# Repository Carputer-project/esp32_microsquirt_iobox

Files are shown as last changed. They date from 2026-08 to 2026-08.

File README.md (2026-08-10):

# ESP32 MicroSquirt I/O box

DIY clone of the official MicroSquirt "I/O-box" — an **ESP32 + SN65HVD230** that
listens to the MS2/Extra MicroSquirt CAN realtime broadcast (base ID `0x5F0`,
500 kbps) and drives **fan**, **idle control (IAC)** and **6 generic low-side
outputs**, with the same fail-safe the real I/O-box uses (outputs off when CAN
goes silent).

Because MS2/Extra has no I/O-box slave protocol (that's an MS3-only feature), this
box is an **autonomous "smart slave"**: it computes its own output logic from the
broadcast data. It also implements the full **Megasquirt 29-bit expansion
protocol** as a responder (so an MS2/Extra master *can* drive its outputs/ADC
directly), and broadcasts a small **`0x710`** frame for the in-dash HMI.

Works with **any MS2/Extra 3.4.x MicroSquirt V3** — no fuel/spark tune changes
needed, only CAN broadcast settings.



## Features

- **Fan** — CLT hysteresis (on ≥ 200 °F / off ≤ 190 °F default, adjustable) or
  manual override, driven through a ULN2003A channel (default O6/GPIO23).
- **IAC** — 30 Hz PWM on GPIO32 → IRLZ44N → 3-wire rotary ISCV. Three modes:
  **Auto** (CLT warm-up table + RPM trim), **Follow** (mirror the ECU's own
  `iacstep` → fully TunerStudio-tunable closed-loop idle), or **Manual**.
- **O1–O6** — generic low-side outputs (ULN2003A): manual, CLT-temp or RPM
  trigger. O1 defaults to a 7000 rpm shift light.
- **Inputs drive outputs** — A1–A4 analog (0-5 V, 0.15 V hysteresis) can force any
  output or the fan (I/O-box parity).
- **29-bit CAN responder** — MS2/Extra remote-port protocol: MSG_REQ/MSG_CMD on
  table 7; remote idle PWM, remote on/off outputs, remote boost, ADC readback.
- **`0x710` dash broadcast** — A1–A4 threshold latches for
  the in-dash HMI (indicator/high-beam/brake icons). 10 Hz, always on.
- **GC9A01A round gauge** — 1.28" 240×240 idle-control display: big IAC duty %,
  RPM / target RPM / CLT / idle mode, fan + CAN status line.
- **Fail-safe** — all outputs off after 500 ms without CAN (matches the real
  I/O-box); IAC falls back to the ~1000-1200 rpm valve default.
- **Persistent config** — all settings stored in NVS; loadable/settable over
  serial or via the included Windows diagnostic app.

## Repo layout

```
esp32_microsquirt_iobox/
├── firmware/            PlatformIO ESP32 firmware — iobox2 (round display)
├── firmware-v3/         PlatformIO ESP32 firmware — iobox3 (configurable pins, display opt-in)
├── pcb/                 KiCad 8 PCB design (iobox2: schematic, board, project)
├── diag/                iobox_diag.py — Windows test/configure app (Python + Tkinter)
└── docs/
    ├── OPERATION.md     How the box works + how to use it (modes, commands, display)
    ├── PROTOCOL.md      CAN protocol reference (0x5F0 broadcast, 0x710, 29-bit responder)
    ├── BUILD.md         Full point-to-point build/wiring guide
    └── PARTS.md         Parts list with rough prices
```

## Two firmware variants

| | `firmware/` (iobox2) | `firmware-v3/` (iobox3) |
|---|---|---|
| Board | ESP32 DevKit + breakout, GC9A01A round display | Bare ESP32-WROOM-32 module board, 7" dash on CAN is the HMI |
| IAC pin | 32 (compile-time) | **runtime-configurable** (`P` command / diag app Pins tab) |
| Outputs | O1-O6 = 25,26,27,14,13,23 (compile-time) | O1-O7 = 13,12,14,27,26,25,33 default, **runtime-configurable** |
| Round display | yes | opt-in (`P TFT 1`; GPIO19 conflicts with IAC) |
| Switches | none (removed) | none |
| Use `P`? | no (fixed pins) | yes |

Both share the same core (CAN broadcast decode, fan, IAC, outputs, engine
profile warnings, 29-bit responder, `0x710` dash broadcast). iobox2 = one build
for that board; iobox3 = one firmware, pin map set once per board via the
diag app.

## Quick start

1. **Build hardware** — see `docs/BUILD.md` (wiring) and `docs/PARTS.md` (parts).
   The KiCad design in `pcb/` is the iobox2 board; the point-to-point
   build guide is an alternative for module wiring without a PCB. iobox3 is the
   bare-module 3×3 board — see `firmware-v3/README.md`.
2. **Flash firmware** (pick the folder matching your board):

   ```sh
   cd firmware        # iobox2  — or:  cd firmware-v3  for iobox3
   pio run                 # build
   pio run --target upload # flash over USB
   pio device monitor -b 115200
   ```

   Requires PlatformIO (ESP32 Arduino framework). At the serial prompt type `?`
   for a live status dump. On iobox3, type `P` to see the pin map (set it once
   from the diag app's Pins tab if your board is wired differently).
3. **Configure the MicroSquirt (one time)** in TunerStudio → CAN Realtime Data
   Broadcasting: **On**, base ID **1520**, rate **20 Hz**, enable groups
   **00** (rpm), **02** (baro/map/mat/clt), **03** (tps/batt/afr), and optionally
   **06** (iacstep) for Follow mode. Details in `docs/OPERATION.md`.
4. **Use the Windows app** (`diag/iobox_diag.py`) to set fan thresholds, IAC mode,
   output triggers, input mappings, the 29-bit responder and (iobox3) the pin map
   from a GUI.

## Hardware snapshot

| GPIO | Function | Drives |
|---|---|---|
| 5 / 4 | CAN TX / RX | SN65HVD230 (MicroSquirt pins 2/3, CANH/CANL) |
| 32 | IAC PWM (30 Hz) | ISCV via IRLZ44N |
| 25,26,27,14,13,23 | O1–O6 | ULN2003A (O6 = fan by default, `Y<k>` to change) |
| 2 | Status LED | onboard (CAN heartbeat / fail-safe blink) |
| 36,39,34,35 | A1–A4 analog 0-5 V | 10k/20k divider (or PCB 12 V→3.3 V dividers) |
| 15,21,22,19 | GC9A01A round display | SCLK / MOSI / CS / DC |

All outputs are **low-side (ground-switching)**, like the real MS I/O-box. Never
feed 12 V into the ESP32 or SN65HVD230 — a 12 V→5 V buck is mandatory.

## Serial command cheat sheet

| Command | Effect |
|---|---|
| `?` | status dump |
| `F205` / `F1` / `F0` | fan auto @205 °F / manual on / off |
| `E190` | fan off hysteresis 190 °F |
| `I35` / `I` / `I F` | IAC manual 35% / auto / follow-ECU |
| `T900` | idle target 900 rpm (auto mode) |
| `S7000` | shift light @7000 rpm |
| `O3 R3500` / `O4 1` | O3 above 3500 rpm / O4 on |
| `A1 O2 3.5` / `A2 F 2.0` | analog threshold → output/fan |
| `Y6` | fan on ULN channel 6 |
| `R1` / `R0` / `RB5` | 29-bit responder on/off / box ID |
| `W1` / `W0` | engine profile monitoring on/off |
| `W idle 650 1000` | idle RPM band (warning below/above, <20% TPS) |
| `W clt 230` / `W mat 160` | max coolant / intake °F |
| `W batt 11.0 16.0` / `W map 280` | battery band / max MAP kPa |
| `W afr 10.0 16.5` | AFR window (below=RICH, above=LEAN) |
| `W hold 3000` / `W warnout 3` | warn latch ms / blink O3 as check-engine lamp |
| `P IAC 19` / `P O3 27` | **iobox3 only** — set IAC / output pin |
| `P RESET` | iobox3 only — restore default pin map |
| `S` | full command list |

## CAN at a glance

- **ECU → box**: 11-bit IDs `0x5F0`–`0x5F8` (group N at ID 1520+N), big-endian,
  8 bytes/group, 20 Hz. rpm@6, baro/map/mat/clt@16-22 (×0.1), tps/batt/afr@24-28
  (×0.1), iacstep@54 (×0.392 = duty %).
- **Box → dash**: `0x710`, byte0 = A1–A4 latches, byte1 = reserved, byte2 = counter.
- **Master → box**: 29-bit extended `MSG_REQ`/`MSG_CMD` (MS2/Extra remote ports).

Full byte maps and the 29-bit responder spec: `docs/PROTOCOL.md`.

## Project context

Built for a 7A-GTE (7A block + 4A-GE head) MicroSquirt V3 car: the I/O box frees
the ECU's FIDLE (moving boost control off it), adds proper PWM idle via the ISCV,
handles the radiator fan, and feeds warning-lamp states (indicators, high beam,
brake) to a 7" ESP32-S3 in-dash HMI. This box is one of several open-source
modules in the [Carputer-project](https://github.com/Carputer-project)
ecosystem.

## License

Firmware, PCB and tooling in this repo are released for personal/DIY use.
See each file header for notes.

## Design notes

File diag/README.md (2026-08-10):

# iobox_diag — Windows test/configure app

Single-file **Python 3 + Tkinter** GUI for the ESP32 MicroSquirt I/O box. It
talks the same text command language the box exposes on its serial console, so
every action maps 1:1 to the serial reference in `../docs/OPERATION.md` §9.

![dependency: python3 + tkinter + optional pyserial]

## Run

```sh
pip install pyserial      # only needed for the USB path
python iobox_diag.py      # python3 on Linux/macOS
```

No Qt needed. Works on Windows too (uses `python`, `pip`).

## What it does

| Tab | Purpose |
|-----|---|
| Fan | auto / manual on-off, on-threshold (°F), off-threshold (°F), output channel (`Y1-7`) |
| IAC | auto / follow-ECU / manual duty, target idle rpm |
| Outputs | per-output manual on/off, temp trigger, rpm trigger (O1-O7) |
| Inputs | A1-A4 analog → target + threshold volts |
| Engine | engine-profile limits grid (idle/maxrpm/clt/mat/batt/map/afr/hold/warnout) |
| Pins | **IAC + output GPIO map** — board presets (iobox2 / iobox3), edit, apply (`P` cmds), read from box |
| Advanced | 29-bit CAN responder enable/disable/box-ID, shift-light rpm |
| Console | raw command line, `?` status button, scrolling RX log |

## Transport

- **USB (default, active)**: `pyserial`, 115200 baud. Pick the COM port and
  Connect.
- **WiFi/TCP**: the radio is currently **disabled** ("WiFi pending (firmware)") —
  the box firmware has no WiFi server yet. The TCP transport code
  (`IoBox.connect_tcp`, default `192.168.4.1:23`) is left in place for when the
  box grows a soft-AP command port.

## Design notes

- `IoBox` class: serial or TCP link, background reader thread → `queue.Queue` →
  `poll()` drains to the UI. `on_line` / `_poll` keep the console live at 50 ms.
- The box persists every setting in NVS; the app just sends commands.
- Status responses (e.g. `?`) come back as `can_fresh=... rpm=...` lines in the
  console — parse-friendly for future automation.

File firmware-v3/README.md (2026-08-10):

# ESP32 MicroSquirt I/O box v3 (iobox3)

Third-generation I/O box for MicroSquirt/MS2-extra. **Single firmware for every
board** — iobox2's round display is merged in (opt-in), and
**output + IAC pins are runtime-configurable** and stored in NVS, so one firmware
serves any WROOM-32 board.

## Pin map (default = iobox3 board)

Configurable at runtime (persisted in NVS) via the `P` command or the diag app's
**Pins** tab:

| Function | Default GPIO | Configurable |
|---|---|---|
| IAC PWM (LEDC 30 Hz) | 19 | yes (`P IAC <pin>`) |
| O1-O7 (ULN2003A low-side) | 13, 12, 14, 27, 26, 25, 33 | yes (`P O<n> <pin>`) |
| CAN TX / RX | 5 / 4 | no (compile-time) |
| Analog A1-A4 | 36, 39, 34, 35 | no (compile-time) |
| Round display (GC9A01A) | 15, 21, 22, 19 | no (compile-time), **opt-in** |
| Status LED | 2 | no (compile-time) |

Board presets are built into the diag app:
- **iobox2**: IAC 32, O1-O6 25/26/27/14/13/23 (+ O7 spare 33), display **on**
- **iobox3**: IAC 19, O1-O7 13/12/14/27/26/25/33, display **off**

Changing a pin takes effect immediately (`applyPinConfig()` reconfigures GPIO modes
and re-attaches LEDC) and survives reboot via NVS.

## Round display (opt-in)

The GC9A01A round gauge (idle duty % center, RPM/TGT/CLT/MODE quadrants, warning
blink, CAN status bar) is compiled in but **disabled by default** because
TFT DC = GPIO19 clashes with iobox3's IAC pin. On a bench dev board (or any board
wired like iobox2) enable it with:

```
P IAC 32    # move IAC off GPIO19 (use the iobox2 preset)
P TFT 1     # enable display (persisted)
```

`P TFT 0` disables it again. The display repaints at 10 Hz.

## Rejected pins

`P` refuses to map these GPIOs (boot straps, console UART, LED, CAN, dead, or
input-only): 0, 1, 2, 3, 4, 5, 6-11, 20, 24, 28-31, 34, 35, 36, 39.

## Serial commands

Everything from iobox2 plus:

| Command | Effect |
|---|---|
| `P` | report current pin map |
| `P IAC 19` | set IAC pin |
| `P O3 27` | set O3 pin |
| `P TFT 1` / `P TFT 0` | enable / disable round display (persisted) |
| `P RESET` | restore iobox3 defaults (persisted) |

Full iobox2 command set (F/E/I/T/Y/S/O/A/R/W) is unchanged — see
`../esp32_ms_iobox/README.md`. The `D` (switch) command is gone — switches were
removed from the firmware.

## Build & flash

```
pio run                         # build
pio run --target upload         # flash over USB
pio device monitor -b 115200    # serial console
```

## Diag app

`~/Desktop/carputer/iobox_diag/iobox_diag.py` gained a **Pins** tab: pick a board
preset, edit the GPIO fields, Apply to box. Read-from-box (`P`) parses the reply
into the fields automatically.

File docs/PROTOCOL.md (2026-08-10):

# CAN protocol reference

Three independent streams live on the bus:

1. **ECU → box**: 11-bit broadcast `0x5F0`+ (MS2/Extra outpc groups).
2. **Box → dash**: 11-bit `0x710` (input states for the in-dash HMI).
3. **Master → box**: 29-bit extended `MSG_REQ` / `MSG_CMD` (Megasquirt expansion
   protocol; MS2/Extra remote ports).

All frames are **500 kbps**. The MicroSquirt V3 has an internal CAN terminator;
the SN65HVD230 module's 120 Ω jumper is the other end of a 2-node bus.

---

## 1. ECU broadcast — `0x5F0` … `0x5F8` (11-bit, 20 Hz, big-endian)

MS2/Extra MicroSquirt broadcasts its `outpc` structure 8 bytes per group, group N
at ID `1520 + N`. Offsets are the `outpc` offsets from `microsquirt-module.ini`
(`ochBlockSize = 212`). Enabled groups: 00, 02, 03 (+ 06 for Follow mode).

| ID | Grp | Byte | Channels (offset, type, scale) |
|----|-----|---|---|
| 0x5F0 | 00 | 0-7 | seconds u16@0, pw1 u16@2, pw2 u16@4, **rpm u16@6** |
| 0x5F1 | 01 | 8-15 | advance s16@8 (×0.1°), flags, afrtgt1/2, wbo2 |
| 0x5F2 | 02 | 16-23 | **baro s16@16**, **map s16@18**, **mat s16@20**, **clt s16@22** (all ×0.1) |
| 0x5F3 | 03 | 24-31 | **tps s16@24**, **batt s16@26**, **afr1 s16@28**, afr2 s16@30 (×0.1) |
| 0x5F4 | 04 | 32-39 | knock u16@32, egocor1 s16@34, egocor2 s16@36, aircor s16@38 |
| 0x5F5 | 05 | 40-47 | warmcor s16@40, tpsaccel s16@42, tpsfuelcut s16@44, barocor s16@46 |
| 0x5F6 | 06 | 48-55 | totalcor s16@48, ve1 s16@50, ve2 s16@52, **iacstep s16@54** |
| 0x5F7 | 07 | 56-63 | coldadv s16@56, TPSdot s16@58, MAPdot s16@60, dwell u16@62 |

Notes:

- All values big-endian; temperatures in °F (×10), pressures in kPa (×10).
- `iacstep` (offset 54) is the ECU's idle valve duty raw 0-255; **duty % =
  `iacstep × 0.392`**. Used by Follow mode (TS `IdleCtl = PWM valve`).
- Group 08 (0x5F8, outpc 64-71) carries portStatus/knockRetard — reserved.

The box's TWAI filter is accept-all (`0xFFFFFFFF`); software ignores IDs outside
`0x5F0`–`0x5F8`, plus `0x600` (commands) and extended frames.

---

## 2. Box → dash — `0x710` (11-bit, 8 bytes, 10 Hz, always on)

Broadcast by the box itself (not the ECU), so it keeps running even if the ECU
bus drops. Carried the input states for the in-dash HMI.

| Byte | Bits | Meaning |
|---|---|---|
| 0 | 0-3 | A1–A4 threshold latches (1 = analog input above its `A<n>` trigger) |
| 1 | — | reserved (0) |
| 2 | all | frame counter (rollover) |
| 3-7 | — | reserved (0) |

The dash decodes this alongside `0x5F0`–`0x5F8` to render indicator / high-beam /
brake icons. The ECU ignores `0x710` (not a group it broadcasts or listens to).

**iobox2 PCB analog dividers** (indicator L, indicator R, high beam, brake
lights): 12 V signals → divider → A1–A4. Ratio must be ≈ 1/4.8 so the GPIO sees
≤ 3.3 V at 14.4 V running voltage. Recommended resistor pairs (series / to-GND):
**33 kΩ / 8.2 kΩ**, 10 kΩ / 2.7 kΩ, 30 kΩ / 7.5 kΩ, or 47 kΩ / 12 kΩ. Avoid
10 kΩ + 3.9 kΩ (≈4.03 V at 14.4 V). Add a 0.1 µF cap GPIO→GND per input; the
firmware's 0.15 V hysteresis is built in. Thresholds are set from what the diag
app reports (board reports GPIO volts × `ADC_DIVIDER` = 1.5).

---

## 3. 29-bit expansion responder — MSG_REQ / MSG_CMD

The box implements the responder side of the Megasquirt 29-bit MS-CAN protocol,
so an MS2/Extra master can directly drive remote outputs and read remote ADC/ports
(MS2/Extra has full remote-port support in 3.4.4 — only the *official* MS2
I/O-box firmware is broadcast-only).

### 3.1 Header (29-bit extended identifier)

```
bit 28 .. 19 : offset      (11 bits, 0x000-0x7FF)
bit 18 .. 16 : type        (3 bits)
bit 15 .. 12 : from_id     (4 bits)
bit 11 ..  8 : to_id       (4 bits)
bit  7 ..  4 : table       (4 bits)
bit  3 ..  0 : table[bit4] (1 bit rides wire bit 2)
```

Equivalently `id = (offset<<18) | (type<<15) | (from<<11) | (to<<7) | (table<<3)`
with the table bit-4 folded into bit 2 (see `respMakeId()` in `main.cpp`).

Types: 0 = MSG_CMD, 1 = MSG_REQ, 2 = MSG_RSP, 4 = MSG_BURN, 5 = OUTMSG_REQ,
6 = OUTMSG_RSP, 12 = MSG_REQX, 0x80 = MSG_PROT, 0x82 = MSG_SPND.

IDs: 0 = ECU, 1-14 = boxes, 15 = broadcast. The ECU accepts `to_id` 0 or 15; the
box accepts `to_id` = its box ID (`respId`, default 5) or 15.

### 3.2 MSG_REQ (read box table) — DLC 3

| DSR | Meaning |
|-----|---|
| 0 | `rem_table` (box echoes it in the reply header) |
| 1 | `rem_off >> 3` (offset bits 10-3) |
| 2 | `((rem_off & 7) << 5) | rem_by` (offset bits 2-0, count 1-8) |

Reply = **MSG_RSP**: header offset = `rem_off` (echo), table = `rem_table` (echo),
from = box, to = requester; DLC = `rem_by`, data = `rem_by` bytes from
`box.tables[rem_table][rem_off]`. The ECU stores the reply into `outpc` at the
echoed offset — **echo `rem_off` and exactly `rem_by` bytes** or the ECU
overwrites unrelated outpc.

### 3.3 MSG_CMD (write box table) — DLC 1-8

Data bytes are stored at `tables[header.table][header.offset]`. For the port
table (default offset 75, auto-detected from the first 1-3 byte write):

| Byte | Meaning |
|---|---|
| 0 | bits 0-5 = O1–O6 on; bit 0x40 = fan on |
| 1 | ISCV duty raw (×100/255 = %) |
| 2 | reserved |

Remote drive is active while port frames stay fresh (< 500 ms); otherwise the
box falls back to autonomous logic, and with no ECU broadcast at all it goes
fail-safe. Input forces (D/A triggers) always OR in.

### 3.4 Box table 7 (256-byte response table)

| Offset | Contents |
|---|---|
| 0-7 | gpioadc0-3 (A1–A4, big-endian mV) |
| 8-15 | gpioadc4-7 (unused, 0) |
| 16-23 | gpiopwmin (unused) |
| 24-74 | free |
| 75-77 | remote ports (see §3.3) |

MSG_REQ reads any offset back; MSG_CMD writes any offset.

### 3.5 TunerStudio setup for remote-port control

```
CAN Parameters        → Master Enable: Enable
Enable poll ports     → enable_pollports: Enable
can_poll_id0-3        → 5 (box ID)
poll_tableports       → 7
poll_offsetports      → 75
ports_dir             → "3 Outputs"
port_generic          → "Remote Port 1"
pwmidle_port2         → "Remote Port 2"
IdleCtl               → PWM valve (open or closed loop)
Group 06              → enable (so Follow-mode fallback + display work)
```

The 0x5F0 broadcast + Follow mode remains available as a parallel, ECU-agnostic
path; the responder and broadcast can be used together or independently.

---

## 4. Box command channel — `0x600` (11-bit, optional)

Any 11-bit frame to ID `0x600` is treated as a serial command string (max 8
bytes, null-terminated): e.g. `F1`, `I F`, `?`. Same parser as the serial port.
Useful for remote reconfiguration over the bus.

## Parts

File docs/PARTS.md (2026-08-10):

# ESP32 MicroSquirt I/O box — Parts list & wiring

Everything needed to build the I/O box. Prices are rough street prices (AliExpress/
DigiKey/Mouser/local); totals assume AliExpress quantities.

## 1. Required parts

| Qty | Part | Purpose | Est. cost |
|-----|---|---|---|
| 1 | ESP32 DevKit (WROOM-32), 30-pin | main controller | $4-8 |
| 1 | SN65HVD230 CAN transceiver module | CAN bus interface (3.3V) | $2-3 |
| 1 | IRLZ44N logic-level N-MOSFET (TO-220) | IAC low-side switch | $1-2 |
| 1 | ULN2003A driver IC (DIP-16 or breakout) | 6 generic low-side outputs O1-O6 (+ fan channel) | $1-2 |
| 1 | 12V→5V buck module (MP1584 / LM2596) | powers logic — do NOT feed 12V into the ESP32 | $2-3 |
| 1 | 4A-GE/7A-FE ISCV (3-wire rotary solenoid) | idle control valve (IAC function only) | spare/used |

Core total: **~$10-20**

## 2. Resistors

| Value | Qty | Where | Required? |
|---|-----|---|---|
| 10kΩ + 20kΩ | 4 pairs | A1-A4 input dividers: sensor → 10k → GPIO, sensor → 20k → GND (GPIO sees 2/3 of input; 0-5V → 0-3.3V) | yes |
| 10kΩ | 1 | gate pull-down on the IRLZ44N gate (keeps MOSFET OFF during ESP32 boot while GPIO floats) | recommended |
| 100Ω-1kΩ | 1 | gate series resistor (slow switching edge, reduce noise) | optional |
| 120Ω | 1 | bus termination — only if the SN65HVD230 module lacks its termination jumper (the MicroSquirt V3 already has its own terminator) | only then |

## 3. Protection components (recommended)

| Part | Qty | Where |
|---|-----|---|
| 1N5404 or 1N4007 flyback diode | 1 | across the ISCV (cathode to +12V) — kills inductive kickback that would destroy the MOSFET. Fan kickback is handled by the ULN2003A internal flyback diodes |
| 0.1µF ceramic cap | 4 | 1 per analog input, GPIO → GND — filters sensor noise |
| Inline fuse 2-5A fast-blow | 1 | on the 12V feed into the buck module |

## 4. Wiring summary

### CAN
```
uS pin 2 (CANH, Blue/Yellow)  → SN65HVD230 CANH
uS pin 3 (CANL, Blue/Red)     → SN65HVD230 CANL
ESP32 GPIO5 (TX)              → SN65HVD230 CTX
ESP32 GPIO4 (RX)              → SN65HVD230 CRX
```
MicroSquirt V3 has an internal terminator; the SN65HVD230 module's 120Ω jumper is the
other end (2-node bus). Keep it ON.

### ESP32 pin map
| GPIO | Function |
|---|---|
| 5 / 4 | CAN TX / RX → SN65HVD230 |
| 32 | IAC PWM → IRLZ44N gate → ISCV |
| 25,26,27,14,13,23 | O1-O6 → ULN2003A inputs (O6 = fan by default) |
| 2 | status LED (onboard) |
| 36,39,34,35 | A1-A4 analog (via 10k/20k divider) |
| 15,21,22,19 | GC9A01 display SCLK/MOSI/CS/DC |

### MOSFET stage (IAC — ×1)
```
GPIO → [optional 100Ω] → gate ── 10kΩ → GND
source → GND
drain  → load low side (load other end to +12V)
flyback diode across load (cathode → +12V)
```

### ULN2003A stage (O1-O6 + fan)
```
GPIO → ULN2003A IN pin directly (built-in 2.7kΩ base resistor)
ULN2003A OUT pin → relay coil / device to +12V (internal flyback diodes)
Fan (default = OUT6): fan − → OUT<fanOut>, fan + → +12V; ULN COM → +12V.
Use a relay for fans drawing > ~500 mA (ULN channel limit).
```

### Analog inputs (×4)
```
sensor signal (0-5V) → 10kΩ → GPIO
                    → 20kΩ → GND
optional 0.1µF cap: GPIO → GND
```

### Switches

None — D1-D3 switch inputs were removed from the firmware. GPIOs 16/17/18 are
unused on the board.

### Power
```
+12V → fuse → buck in → 5V out → ESP32 5V pin
ESP32 GND = buck GND = SN65HVD230 GND = uS signal ground (all common)
```

## 5. Notes / cautions

- **Never** feed 12V into the ESP32 or SN65HVD230 — the buck module is mandatory.
- ISCV is a **3-wire rotary solenoid** (center = +12V, one outer = GND, one outer =
  IRLZ44N drain). PWM duty >50% opens, <50% closes — swap the outer pins to invert.
  Do NOT use a stepper driver with this valve.
- If running the IAC output, leave the 3.3V/5V off the gate — these are low-side,
  ground-switching drivers.
- All outputs are low-side (ground-switch) exactly like the real MS I/O-box.
- Fan rides a ULN2003A channel (`fanOut`, default 6 = O6). ULN channels are ~500 mA —
  run a big radiator fan through a relay driven by a ULN channel instead.

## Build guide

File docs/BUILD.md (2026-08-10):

# ESP32 MicroSquirt I/O box — Point-to-point build

DIY clone of the MS I/O-box: ESP32 + SN65HVD230 reads the MicroSquirt CAN broadcast
(base ID 0x5F0, 500k) and drives fan, IAC, and 6 generic low-side outputs. Fail-safe:
all outputs off after 500 ms no CAN.

Build style: **module-to-module point-to-point wiring** — no unified PCB. ESP32 comes
with a pinout board / screw terminals; every module (CAN transceiver, MOSFETs, ULN2003A,
buck) wires directly to it.

---

## 1. Block diagram

```
                        ┌──────────────────────────────┐
                        │         +12V switched         │
                        └──────┬───────────────────────┘
                               │
                          [ 2-5A fuse ]
                               │
                       ┌───────┴────────┐
                       │  MP1584/LM2596 │  buck 12V→5V
                       │  buck module   │
                       └───┬────────┬───┘
                           │ 5V     │ GND
                           │        │
        ┌──────────────────┼────────┼──────────────────────────┐
        │                  │        │                          │
   ┌────┴─────┐      ┌─────┴────┐   │                    ┌─────┴─────┐
   │  ESP32   │      │SN65HVD230│   │                    │  MicroSq. │
   │ DevKit   │      │ CAN trx  │   │                    │  V3 (uS)  │
   │ 30-pin   │      │          │   │                    │           │
   └─┬──┬──┬──┘      └──┬────┬──┘   │                    └─────┬─────┘
     │  │  │            │    │      │                          │
     │  │  │   GPIO4 RX─┘    └─GPIO5 TX                       │
     │  │  │            │          │                          │
     │  │  │       CANH └──────────┼────────── uS pin 2 (CANH, Blue/Yellow)
     │  │  │       CANL ───────────┼────────── uS pin 3 (CANL, Blue/Red)
     │  │  │                       │
     │  │  │   (120Ω termination on SN65HVD230 jumper — uS has its own)
     │  │  │
     │  │  └── GPIO32 → IRLZ44N → ISCV (IAC, 30 Hz PWM)
     │  │
      ├── GPIO25,26,27,14,13,23 → ULN2003A IN1-IN6 → O1-O6 (relays/loads)
      │  │     fan = ULN channel (default O6/GPIO23, Y<k> command to change)
      ├── GPIO2  → status LED (onboard)
      ├── GPIO36,39,34,35 → A1-A4 (0-5V via 10k/20k divider)
      └── GPIO15,21,22,19 → GC9A01 round display (SCLK, MOSI, CS, DC)
```

---

## 2. Wiring diagram (point-to-point)

### 2.1 Power

```
+12V (switched) ──[fuse 2-5A]──┬─ buck IN+
                               └─ fan/ISCV/relay +12V rail
buck OUT 5V ── ESP32 "5V" pin
buck GND ───── ESP32 GND + SN65HVD230 GND + uS signal GND (all common)
```

### 2.2 CAN (MicroSquirt → SN65HVD230 → ESP32)

```
uS pin 2 (CANH, Blue/Yellow) ── SN65HVD230 CANH
uS pin 3 (CANL, Blue/Red)    ── SN65HVD230 CANL
ESP32 GPIO5 (TX)             ── SN65HVD230 CTX
ESP32 GPIO4 (RX)             ── SN65HVD230 CRX
SN65HVD230 120Ω jumper: ON
```

### 2.3 IAC stage — confirmed: 7A rotary-solenoid ISCV (3-wire)

Customer's valve is the **7A-FE/4A-FE rotary solenoid ISCV** (NOT a stepper). 3-wire
connector: **center = +12V (switched)**; one outer pin = **ground**; one outer pin =
**ECU low-side PWM** (IRLZ44N on GPIO32). Duty ratio: **>50% opens, <50% closes**
(swap the two outer pins to invert if it responds backwards). Unpowered, the valve
rests at ~1000-1200 rpm — a natural fail-safe (CAN loss → valve stays near default).

```
+12V rail ── ISCV center pin (+B)
ISCV outer pin (E1/ground side) ── GND
ESP32 GPIO32 ──[100Ω]── gate ──[10kΩ]── GND   (IRLZ44N)
               source ── GND
               drain  ── ISCV remaining outer pin (PWM control)
               [1N5404 across ISCV, cathode→+12V, anode→drain]
```

Firmware: existing PWM mode on GPIO32 already correct (30 Hz low-side duty).
Only tuning: map duty so >50% = open (or rewire outer pins to invert).

**Option B — 4-wire stepper ISCV (22270-16010/16020): H-bridge/stepper driver**

A stepper has 2 coils (4 wires) and CANNOT be driven by one PWM channel. Use a
stepper driver (DRV8825/A4988) or dual H-bridge (L298N).

**NOTE**: the old design reserved GPIO21+GPIO22 for the stepper. Those are now used by
the round display (MOSI, CS). The stepper option is demoted — if a 4-wire valve ever
shows up, rewire the display elsewhere (or run it on a second ESP32). The confirmed
3-wire rotary ISCV (Option A above) is the only supported IAC path. Stepper firmware
is also still pending — current `main.cpp` outputs PWM on GPIO32 only (Option A).

### 2.4 Fan stage (via ULN2003A channel, default O6/GPIO23)

**There is NO dedicated fan MOSFET.** The firmware drives the fan through one of the
ULN2003A channels — `Cfg.fanOut` (default **6** = GPIO23/O6, set with the `Y<k>`
serial command, `Y0` = off). `setFan()` in `main.cpp:127` just pokes that channel and
the output loop skips it (main.cpp:329).

```
fan + wire ── +12V rail
fan − wire ── ULN OUT<fanOut>   (e.g. OUT6)
fan control wire ── (ULN COM → +12V already provides internal flyback)
```

- **Inductive kickback**: handled by the ULN2003A built-in flyback diodes (COM must be
  tied to +12V). No external 1N5404 needed on the fan.
- **Current**: ULN2003A channels are ~500 mA continuous / 350 mA per-channel worst-case
  daisy-chained. If the radiator fan draws more, drive a **relay** from a ULN channel
  instead (ULN OUT → relay coil → +12V, relay contacts switch the fan).
- Default output is O6; if you want the fan on a different channel, set `Y<k>` and wire
  that OUT pin to the fan.

### 2.5 Generic outputs (ULN2003A)

```
ESP32 GPIO25 ── ULN IN1 │ OUT1 ── O1 (shift light 7000 rpm)
ESP32 GPIO26 ── ULN IN2 │ OUT2 ── O2
ESP32 GPIO27 ── ULN IN3 │ OUT3 ── O3
ESP32 GPIO14 ── ULN IN4 │ OUT4 ── O4
ESP32 GPIO13 ── ULN IN5 │ OUT5 ── O5
ESP32 GPIO23 ── ULN IN6 │ OUT6 ── O6 (fan by default — see §2.4)
ULN COM pin ── +12V rail (internal flyback diodes need this)
Each OUT n ── load low side; load + side ── +12V
```

### 2.6 Analog inputs (×4) — 0-5V → 3.3V

```
sensor sig (0-5V) ──[10kΩ]── GPIO36 (A1)
                 └──[20kΩ]── GND
optional 0.1µF cap: GPIO ── GND
same divider for A2/A3/A4 → GPIO39/34/35
```

### 2.7 Analog inputs (A1-A4) — see §2.9 pin table

The box has no switch inputs (D1–D3 removed from firmware). All four GPIO pins
that formerly served switches are unused/available.

### 2.8 Round display (GC9A01A 240×240) — 4-wire SPI

```
display VCC ── 5V      display GND ── GND
display SCL ── GPIO15   display SDA ── GPIO21
display CS  ── GPIO22   display DC  ── GPIO19
display RST ── 3V3 (tied high; reset handled at power-up)
```

Software SPI via the Adafruit GC9A01A library (hardware SPI pins 15/21/22/19 are in
use by other channels). Renders an idle-control gauge: big IAC duty %, actual RPM /
target RPM / CLT / idle mode (AUTO·FOLLOW·MAN), and a bottom fan + CAN status line
(red "CAN LOST" on fail-safe).

### 2.9 Status LED

```
GPIO2 ── onboard LED (CAN heartbeat)   [no wiring needed]
```

---

## 3. ESP32 pin map (summary)

| GPIO | Function | Drives |
|---|---|---|
| 5 | CAN TX | SN65HVD230 CTX |
| 4 | CAN RX | SN65HVD230 CRX |
| 32 | IAC PWM | ISCV via IRLZ44N (30 Hz) |
| 25 | O1 shift light | ULN2003A |
| 26 | O2 | ULN2003A |
| 27 | O3 | ULN2003A |
| 14 | O4 | ULN2003A |
| 13 | O5 | ULN2003A |
| 23 | O6 — fan (default) | ULN2003A |
| 2 | Status LED | onboard |
| 15 | Display SCLK | GC9A01 round display |
| 21 | Display MOSI | GC9A01 round display |
| 22 | Display CS | GC9A01 round display |
| 19 | Display DC | GC9A01 round display |
| 36,39,34,35 | A1-A4 analog 0-5V | via 10k/20k divider to 3.3V |

---

## 4. Parts list

### Required

| Qty | Part | Purpose | Est. cost |
|-----|---|---|---|
| 1 | ESP32 DevKit (WROOM-32) 30-pin with pinout board + screw terminals | main controller | $4-8 |
| 1 | SN65HVD230 CAN transceiver module | CAN interface (3.3V), 120Ω jumper | $2-3 |
| 1 | IRLZ44N logic-level N-MOSFET (TO-220) | IAC low-side | $1-2 |
| 1 | ULN2003A driver IC (DIP-16 or breakout) | O1-O6 low-side + fan channel | $1-2 |
| 1 | 12V→5V buck module (MP1584 / LM2596) | logic power — never feed 12V to ESP32 | $2-3 |
| 1 | ISCV (7A-FE/4A-FE rotary solenoid, **3-wire**) | IAC valve | on car |
| 1 | 1.28" round GC9A01A TFT 240×240 (e.g. Teyleten B0B7TFRNN1) | info gauge, SPI | $3-5 |
| 0-1 | **DRV8825/A4988 or L298N** (only if a 4-wire stepper ISCV is ever used) | stepper driver — NOTE: GPIO21/22 now used by display | $2-4 |

### Resistors

| Value | Qty | Where |
|---|-----|---|
| 10kΩ | 4 | A1-A4 dividers (sensor → GPIO) |
| 20kΩ | 4 | A1-A4 dividers (sensor → GND) |
| 10kΩ | 1 | gate pull-down on IRLZ44N (keeps MOSFET off during ESP32 boot) |
| 100Ω | 1 | optional gate series (noise) |
| 100µF electrolytic | 1 | bulk cap across DRV8825 VMOT/GND (only for stepper option) |

### Protection

| Part | Qty | Where |
|---|-----|---|
| 1N5404 flyback diode | 1 | across ISCV (cathode → +12V). Fan kickback is handled by ULN2003A internal diodes |
| 0.1µF ceramic cap | 4 | 1 per analog input, GPIO → GND |
| 2-5A fast-blow inline fuse | 1 | 12V feed into buck |
| 120Ω resistor | 1 | only if SN65HVD230 module lacks termination jumper |

### Wire / hardware

| Item | Qty | Purpose |
|---|-----|---|
| 18-22 AWG wire (various colors) | roll | power + loads |
| 24 AWG hookup wire | roll | signals (CAN, GPIO) |
| Heat shrink / solder / flux | — | joints |
| Small enclosure or mounting plate | 1 | mount modules |
| Ring/spade terminals + M3 bolts | — | IRLZ44N TO-220 mounting |

---

## 5. Build order (suggested)

1. Buck module: fuse → 12V in, set 5V out, verify with multimeter before connecting ESP32
2. CAN: SN65HVD230 → ESP32 GPIO4/5, then MicroSquirt pins 2/3 (only after power check)
3. MOSFET stage: IRLZ44N + gate pull-down + flyback diode (IAC only)
4. ULN2003A: COM to +12V, wire O1-O6 (+ fan on its channel)
5. Analog dividers A1-A4 + caps
6. Round display: SCL→15, SDA→21, CS→22, DC→19, RST→3V3
7. Flash firmware, bench-test with CAN sniffer, then install

## 6. TunerStudio setup (one-time, on the MicroSquirt)

1. `CAN Parameters` → Master Enable `Enable` (already set in 7A-GTE tune)
2. `CAN Realtime Data Broadcasting`:
   - Enable realtime data broadcasting over CAN = **On**
   - Base message identifier = **1520**
   - Broadcasting rate = **20 Hz**
   - Enable groups **00** (rpm), **02** (baro/map/mat/clt), **03** (tps/batt/afr)

## 7. Cautions

- **Never** feed 12V into ESP32 or SN65HVD230 — buck is mandatory.
- **Fan rides a ULN2003A channel (default O6/GPIO23, `Y<k>` to change)** — no dedicated
  MOSFET. ULN channels are ~500 mA: use a relay for a big radiator fan.
- **ISCV = 7A rotary solenoid (3-wire)**: center +12V, one outer to GND, one outer to
  IRLZ44N drain. Duty >50% opens, <50% closes. Swap the two outer pins if inverted.
  Do NOT use a stepper driver with this valve.
- All outputs are low-side (ground-switch), like the real MS I/O-box.
- CAN loss leaves the rotary ISCV at its ~1000-1200 rpm default (natural fail-safe);
  set the base idle screw below that so the box controls idle.

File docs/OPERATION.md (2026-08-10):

# Operation & how to use

This document describes how the I/O box behaves and how to configure and drive
it. For wiring and parts see `BUILD.md` / `PARTS.md`; for the raw CAN byte maps
see `PROTOCOL.md`.

## 1. What the box does

The box sits on the MicroSquirt CAN bus and:

1. **Reads** the MS2/Extra realtime broadcast (`0x5F0`+groups) for rpm, MAP,
   MAT, CLT, TPS, battery, AFR and (optionally) the ECU's own idle step.
2. **Computes** its own output states: fan from CLT hysteresis, IAC from a
   warm-up table + RPM trim (or mirrors the ECU's `iacstep`), O1–O6 from
   manual/temp/rpm triggers, plus input-forced overrides.
3. **Acts** through low-side drivers (ULN2003A for fan + O1–O6, IRLZ44N for the
   ISCV).
4. **Reports** on the round GC9A01A display and via a serial console.

MS2/Extra has no I/O-box slave protocol (MS3-only), so the box is an autonomous
"smart slave" — its logic lives in firmware/config, not in TunerStudio. It also
implements the 29-bit Megasquirt expansion protocol as a responder so the ECU
*master* can drive it directly when configured for remote ports (see §7).

## 2. Power-up / boot

- On boot the box draws the gauge frame, loads its NVS config, zeroes all
  outputs (fail-safe start) and starts CAN.
- Serial prints `MS2/Extra I/O box ready. Type ? for status.` at 115200 baud.
- Until the first CAN frame arrives the box holds all outputs off and IAC at
  `iacFailDuty` (default 0).

## 3. CAN data the box needs

TunerStudio → **CAN Realtime Data Broadcasting** (MicroSquirt):

| Setting | Value |
|---|---|
| Enable realtime broadcasting over CAN | On (`can_outpc_gp00_master`) |
| Base message identifier | 1520 |
| Broadcasting rate | 20 Hz |
| Groups | **00** (rpm), **02** (baro/map/mat/clt), **03** (tps/batt/afr) |
| Optional | **06** (totalcor/ve/iacstep) for Follow mode |

Group N is broadcast at ID `1520 + N` whether or not it is enabled; enabling a
group just turns its transmission on. IDs are fixed — the box needs no
reconfiguration if you add groups later.

### Group gating

- Missing group 00 → RPM reads 0 and RPM triggers/display RPM stay dead.
- Missing group 02 → CLT is invalid: fan stays off (unless manual/forced) and
  IAC auto falls back to the 120 °F interpolated duty.
- Missing group 06 → Follow mode falls back to the auto CLT table (never to a
  closed valve).
- No frame at all for **500 ms** → full fail-safe: fan off, O1–O6 off, IAC =
  `iacFailDuty`. The display shows **CAN LOST** and the LED blinks fast.

## 4. Output logic

### 4.1 Fan

Priority (first true wins): **input-forced** → **29-bit remote port bit** →
**auto CLT hysteresis** → **manual**.

- Auto: on when CLT ≥ `fanOnTemp` (default 200 °F), off when CLT ≤ `fanOffTemp`
  (default 190 °F). Hysteresis prevents relay chatter.
- Manual: `F1` / `F0` pins it on/off.
- Channel: the fan rides a ULN2003A output selected by `fanOut` (default **6** =
  O6/GPIO23). `Y<k>` moves it to channel k (1–6) or off (0). The chosen channel
  is skipped by the O1–O6 loop.
- ULN2003A channels are rated ~500 mA — drive a big radiator fan through a relay
  powered by a ULN channel instead of directly.

### 4.2 IAC (idle control)

Three modes, selected with `I`:

| Mode | Command | Behavior |
|---|---|---|
| **Auto** (default) | `I` or `I A` | Open-loop duty from a CLT table (60% @50 °F → 28% @200 °F, interpolated) plus an RPM trim: target `iacTargetRpm` (default 900), +8%/−5% duty max. |
| **Follow** | `I F` | Mirrors the ECU's own idle output: MS2/Extra broadcasts its valve duty as `iacstep` (group 06, offset 54, ×0.392 = duty %). Enable MS2 native idle (`IdleCtl = PWM valve`, open-loop or closed-loop) in TS and the box becomes a pure amplifier for **fully TS-tunable idle** — target rpm, warm-up curve, PID, all from TunerStudio. No local RPM trim (the ECU already has feedback). Group 06 missing → falls back to auto. |
| **Manual** | `I35` | Fixed duty for testing. |

Output: 30 Hz PWM on GPIO32 → IRLZ44N low-side → 3-wire rotary ISCV. The
7A/4A rotary valve opens above ~50 % duty and closes below; if the response is
inverted, swap the two outer wires on the valve connector.

### 4.3 O1–O6

Each output has a mode: **off**, **manual** (`1`/`0`), **temp** (`T<°F>`, needs
valid CLT), or **rpm** (`R<rpm>`, needs group 00). Defaults: O1 = shift light
@7000 rpm (single threshold with natural hysteresis), O2–O6 off. `S<rpm>`
reconfigures O1 to the given rpm.

Input-forced overrides apply on top of any mode (see §5).

### 4.4 Fail-safe

- ECU CAN silent for 500 ms → fan + O1–O6 off, IAC = `iacFailDuty` (default 0),
  display status goes red **CAN LOST**, LED blinks at 120 ms.
- The engine keeps running on the mechanical base idle — set the throttle stop
  ~700 rpm so the car idles even with the ISCV fully closed.
- The rotary ISCV unpowered rest is ~1000-1200 rpm — a natural safety net.

## 5. Inputs drive outputs

### 5.1 Analog inputs A1–A4 (0-5 V, 0.15 V hysteresis)

| Command | Meaning |
|---|---|
| `A1 O2 3.5` | A1 above 3.5 V → force O2 on |
| `A2 F 2.0` | A2 above 2.0 V → force fan on |
| `A3 4.2` | set A3 threshold 4.2 V, keep current target |
| `A4 0` | disable A4 trigger |

Hysteresis: input must fall 150 mV below the threshold to release, preventing
chatter. **On the iobox2 PCB these four inputs are wired to 12 V→3.3 V dividers**
for the dash indicator signals — set the thresholds from what the diag app reads
(see `PROTOCOL.md` §4 for the 0x710 frame and divider values).

(Switch inputs D1–D3 were removed from the firmware.)

## 6. Display (GC9A01A round 240×240)

Idle-control focused, refreshed at 10 Hz:

- **Big center**: current IAC duty %.
- **Quadrants**: RPM (white), target RPM (yellow), CLT °F (yellow), idle MODE
  (AUTO / FOLLOW / MAN / RMT). CLT and RPM show `--` while a group is missing.
- **Bottom line**: `FAN ON/OFF  CAN OK` (green/light-grey) or `CAN LOST` (red).
- RMT mode (29-bit remote driving the ports) shows magenta.

Pin map: SCL→15, MOSI/SDA→21, CS→22, DC→19, RST→3V3, VCC→5V.

## 7. 29-bit CAN responder (MS2/Extra remote ports)

The box answers the Megasquirt expansion protocol (29-bit extended frames) so an
MS2/Extra master can directly drive its outputs and read its inputs:

| Serial | Effect |
|---|---|
| `R1` | enable responder |
| `R0` | disable (default) |
| `RB5` | set box ID (1–14; default 5 — matches TS `can_poll_id0-3`) |

When a fresh remote **port frame** is present the remote bytes drive the box:
byte0 bits 0-5 = O1–O6, bit 0x40 = fan, byte1 = ISCV duty (×100/255). Input
forces still OR in. If the port frames go stale (>500 ms) the box falls back to
autonomous logic; if the ECU broadcast is gone entirely it goes fail-safe.

Full wire format, reply echo rules and TS config for remote ports:
`docs/PROTOCOL.md` §3.

## 8. Windows diagnostic app (`diag/iobox_diag.py`)

Single-file Python 3 + Tkinter tool that talks the same serial command language
over USB (WiFi/TCP transport is in the code but the box firmware has no WiFi
server yet — use USB).

```sh
pip install pyserial      # only needed for the USB path
python iobox_diag.py      # or python3
```

- **Connection bar**: pick the USB COM port (Refresh scans), Connect.
- **Fan tab**: auto/manual, on/off thresholds, output channel (`Y`).
- **IAC tab**: auto / follow / manual duty, target rpm.
- **Outputs tab**: per-output manual on/off, temp and rpm triggers.
- **Inputs tab**: A1–A4 → target output mappings.
- **Advanced tab**: 29-bit responder enable/disable/ID, shift-light rpm.
- **Console**: raw command entry, `?` status button, scrolling RX log — every
  command shown here maps 1:1 to the serial reference below.

## 9. Serial command reference (115200 baud)

| Command | Effect |
|---|---|
| `?` | status dump: can fresh, rpm, map, mat, clt, tps, batt, afr, fan, iac mode/duty, responder state/ports, output states, input voltages/states |
| `F` | fan auto, default thresholds |
| `F205` | fan auto, on ≥ 205 °F |
| `F1` / `F0` | fan manual on / off |
| `E190` | fan off (hysteresis) ≤ 190 °F |
| `I35` | IAC manual 35 % |
| `I` / `I A` | IAC auto (CLT table + RPM trim) |
| `I F` | IAC follow-ECU (`iacstep`; needs group 06 + TS `IdleCtl = PWM`) |
| `T900` | IAC target idle 900 rpm (auto mode) |
| `S7000` | shift light threshold 7000 rpm (O1) |
| `Y6` | fan on ULN channel 6 (1–6, 0 = off) |
| `O2 1` / `O2 0` | O2 manual on / off |
| `O3 T210` | O3 on when CLT ≥ 210 °F |
| `O4 R3500` | O4 on when rpm ≥ 3500 |
| `O5 A` | O5 auto/off (clear mode) |
| `A1 O2 3.5` | A1 above 3.5 V forces O2 |
| `A2 F 2.0` | A2 above 2.0 V forces fan |
| `A3 4.2` | set A3 threshold only |
| `A4 0` | disable A4 |
| `R1` / `R0` | 29-bit responder on / off |
| `RB5` | responder box ID = 5 |
| `S` | print the full command list |

All settings are written to NVS (stored with a magic/version word; a stored
config of the wrong size or without the magic is discarded and defaults are
rewritten).

## 10. Bench-testing checklist

Before installing in the car:

1. Flash + serial: `?` works, status shows `can_fresh=0`.
2. Second ESP32 + SN65HVD230 broadcasting synthetic outpc (groups 00/02/03, 20
   Hz): `can_fresh=1`, rpm/CLT/AFR appear on `?` and the display.
3. Fan: `F1` → fan channel goes low-side on; `F0` off; `F200`/`E190` with a fake
   CLT → hysteresis toggles.
4. IAC: `I60` → ISCV PWM; `I F` + synthetic group 06 → duty tracks `iacstep`;
   `T<rpm>` changes the target shown on the display.
5. Inputs: ground a D pin → forced output; feed a voltage above/below an A
   threshold → latch + release (0.15 V hysteresis).
6. Responder: send a 29-bit MSG_CMD port frame (box ID 5) → O1–O6/fan/IAC follow
   the port bytes; stop sending → falls back to autonomous within 500 ms.
7. `0x710`: sniff the bus — 8-byte frame every 100 ms, byte0/byte1 track the A/D
   input states.
8. Cut CAN entirely → all outputs off, display `CAN LOST`, LED fast-blink.

## 11. Integration notes (7A-GTE)

- The I/O box frees **FIDLE** — the boost solenoid can move to TACHOUT; the box
  never touches the ECU's boost output.
- On this car the ISCV was blocked off and idle ran at 1600 rpm via the manual
  screw. Sequence: unblock the ISCV → wire it to the box IAC → set the manual
  screw base idle ~700 rpm → let the box close-loop the rest (do this in the shop
  with the wideband live).
- **Before the first start after any tune change**: the box's injector-PWM fix
  (`injctl2_1=On`, `injPwmP=30`) must be loaded and burned on the ECU side —
  see the AGENTS.md project notes for the 7A-GTE specifics.

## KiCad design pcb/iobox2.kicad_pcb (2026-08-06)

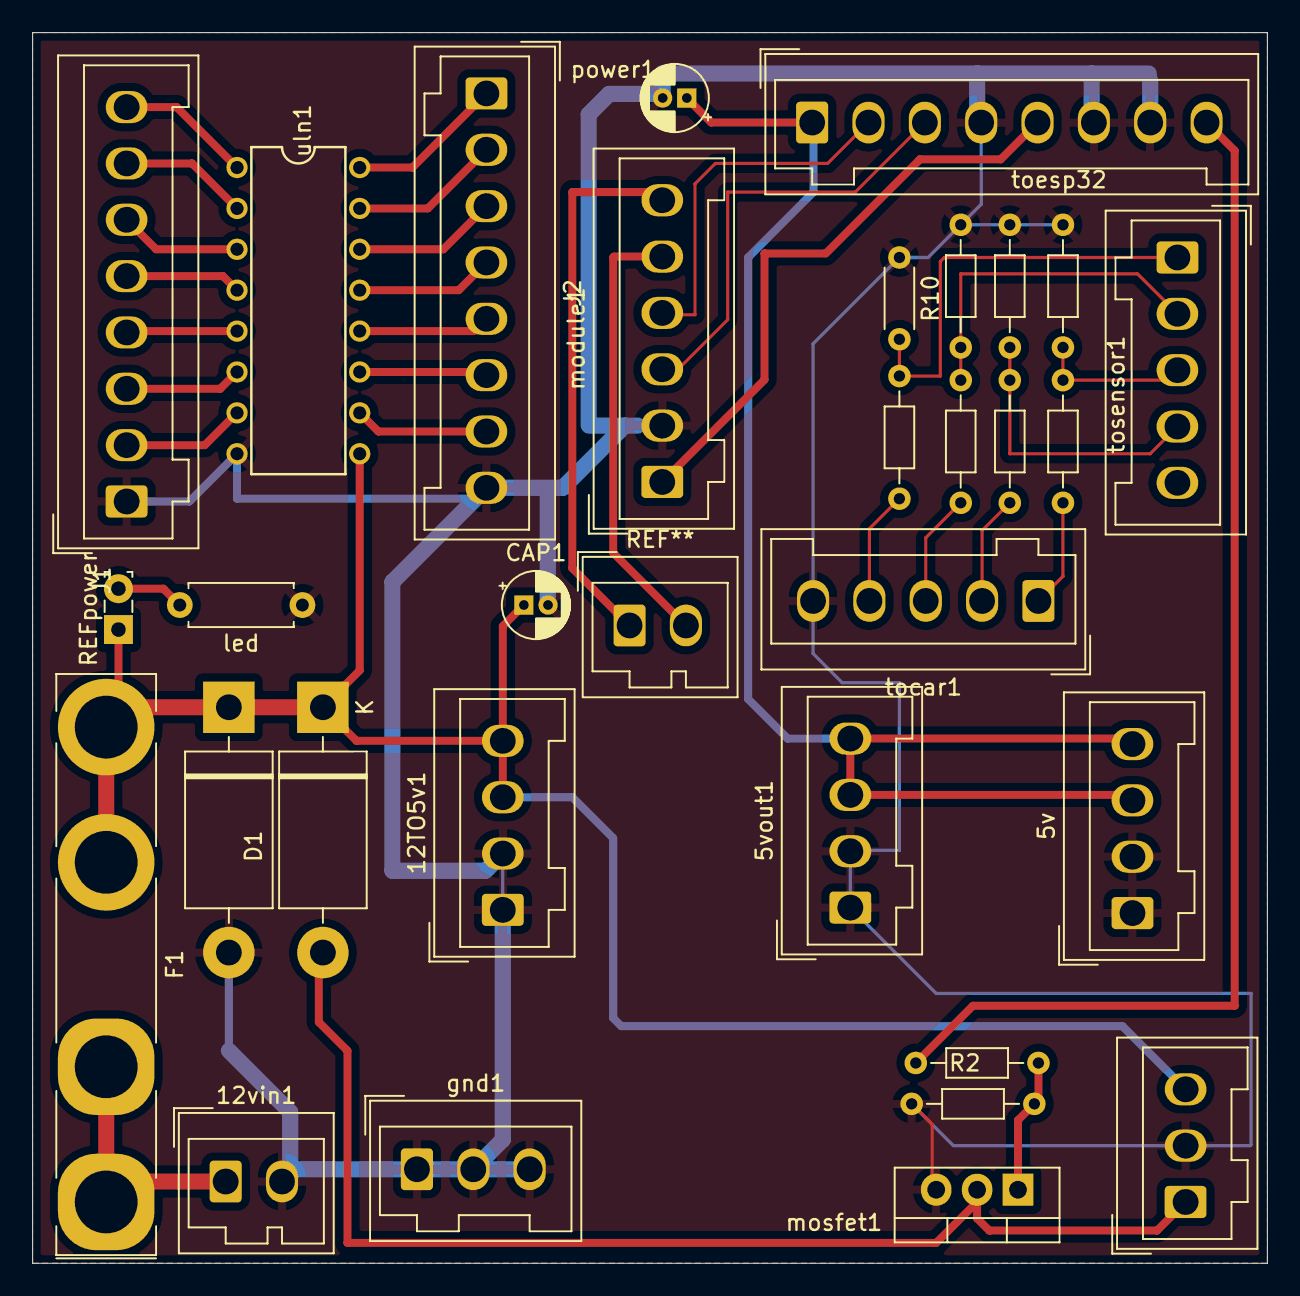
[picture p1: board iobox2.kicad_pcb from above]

Board: 2 copper layers, 76.7 x 76.5 mm, 31 parts (0 on the bottom side), 32 nets.

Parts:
5v: 5v; Wago_734-134_1x04_P3.50mm_Vertical
5vout1: 5vout; Wago_734-134_1x04_P3.50mm_Vertical
12TO5v1: 12v-5v; Wago_734-134_1x04_P3.50mm_Vertical
12vin1: 12v in; Wago_734-132_1x02_P3.50mm_Vertical
CAP1: CAP; CP_Radial_D4.0mm_P1.50mm
D1, D2: 1N5404; D_DO-201AD_P15.24mm_Horizontal
F1: Fuse; Fuseholder_Keystone_3555-2
IDLE1: IAC; Wago_734-133_1x03_P3.50mm_Vertical
J1, J2: Conn_01x08; Wago_734-138_1x08_P3.50mm_Vertical
R1, R2, R3, R4, R5, R6, R7, R8, R9: R; R_Axial_DIN0204_L3.6mm_D1.6mm_P7.62mm_Horizontal
R10: R; R_Axial_DIN0204_L3.6mm_D1.6mm_P5.08mm_Horizontal
REFpower: led; LED_SideEmitter_Rectangular_W4.5mm_H1.6mm
gnd1: gnd; Wago_734-133_1x03_P3.50mm_Vertical
led: lr; R_Axial_DIN0207_L6.3mm_D2.5mm_P7.62mm_Horizontal
module1: canbus; Wago_734-136_1x06_P3.50mm_Vertical
mosfet1: IRLZ44N; TO-220-3_Vertical
power1: capp; CP_Radial_D4.0mm_P1.50mm
tocar1: CAR; Wago_734-135_1x05_P3.50mm_Vertical
toesp32: ESP32; Wago_734-138_1x08_P3.50mm_Vertical
tosensor1: sensor; Wago_734-135_1x05_P3.50mm_Vertical
uln1: ULN2002A; DIL16

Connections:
+3.3V: module1.1, toesp32.5
+5V: 5v.3, 5v.4, 5vout1.3, 5vout1.4, power1.1, toesp32.1
GND: 5v.1, 5v.2, 5vout1.1, 5vout1.2, 12TO5v1.1, 12TO5v1.2, 12vin1.2, CAP1.2, D1.2 (A), IDLE1.2, J1.1, J2.8, R1.2, R4.1, R6.1, R8.1, R10.1, gnd1.1, gnd1.2, gnd1.3, led.1, module1.2, mosfet1.3 (S), power1.2, tocar1.5, toesp32.4, toesp32.6, toesp32.7, uln1.8 (GND)
unnamed: 12TO5v1.3, 12TO5v1.4, CAP1.1, D1.1 (K), D2.1 (K), F1.2, IDLE1.3, REFpower.1, uln1.9 (COM)
unnamed: 12vin1.1, F1.1
unnamed: D2.2 (A), IDLE1.1, mosfet1.2 (D)
unnamed: J1.2, uln1.7 (I7)
unnamed: J1.3, uln1.6 (I6)
unnamed: J1.4, uln1.5 (I5)
unnamed: J1.5, uln1.4 (I4)
unnamed: J1.6, uln1.3 (I3)
unnamed: J1.7, uln1.2 (I2)
unnamed: J1.8, uln1.1 (I1)
unnamed: J2.1, uln1.16 (O1)
unnamed: J2.2, uln1.15 (O2)
unnamed: J2.3, uln1.14 (O3)
unnamed: J2.4, uln1.13 (O4)
unnamed: J2.5, uln1.12 (O5)
unnamed: J2.6, uln1.11 (O6)
unnamed: J2.7, uln1.10 (O7)
unnamed: module1.3, toesp32.3
unnamed: module1.4, toesp32.2
unnamed: R1.1, R2.1, mosfet1.1 (G)
unnamed: R3.2, tocar1.1
unnamed: R5.2, tocar1.2
unnamed: R7.2, tocar1.3
unnamed: R9.2, tocar1.4
unnamed: R2.2, toesp32.8
unnamed: R9.1, R10.2, tosensor1.1
unnamed: R7.1, R8.2, tosensor1.2
unnamed: R3.1, R4.2, tosensor1.3
unnamed: R5.1, R6.2, tosensor1.4

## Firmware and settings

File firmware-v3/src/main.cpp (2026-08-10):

#include <Arduino.h>
#include <driver/twai.h>
#include <Preferences.h>
#include <SPI.h>
#include <Adafruit_GFX.h>
#include <Adafruit_GC9A01A.h>

static constexpr uint8_t PIN_CAN_TX = 5;
static constexpr uint8_t PIN_CAN_RX = 4;
static constexpr uint8_t PIN_LED = 2;

static constexpr uint8_t PIN_A1 = 36;
static constexpr uint8_t PIN_A2 = 39;
static constexpr uint8_t PIN_A3 = 34;
static constexpr uint8_t PIN_A4 = 35;

static constexpr uint8_t PIN_TFT_SCLK = 15;
static constexpr uint8_t PIN_TFT_MOSI = 21;
static constexpr uint8_t PIN_TFT_CS   = 22;
static constexpr uint8_t PIN_TFT_DC   = 19;
static Adafruit_GC9A01A s_tft(PIN_TFT_CS, PIN_TFT_DC, PIN_TFT_MOSI, PIN_TFT_SCLK, -1);

// Default pin map (iobox3 / v3 board). Runtime-configurable via 'P' command.
static constexpr uint8_t PIN_IAC_DEF = 19;
static constexpr uint8_t PIN_O1_DEF  = 13;
static constexpr uint8_t PIN_O2_DEF  = 12;
static constexpr uint8_t PIN_O3_DEF  = 14;
static constexpr uint8_t PIN_O4_DEF  = 27;
static constexpr uint8_t PIN_O5_DEF  = 26;
static constexpr uint8_t PIN_O6_DEF  = 25;
static constexpr uint8_t PIN_O7_DEF  = 33;

static constexpr uint32_t CAN_BASE_ID = 0x5F0;
static constexpr uint8_t  CAN_GROUP_COUNT = 9;
static constexpr uint32_t CAN_CMD_ID = 0x600;
static constexpr uint32_t CAN_DASH_ID = 0x710;
static constexpr uint16_t DASH_TX_MS = 100;
static constexpr uint32_t FAILSAFE_MS = 500;
static constexpr float    ADC_DIVIDER = 1.5f;

static constexpr uint8_t  MSG_CMD    = 0;
static constexpr uint8_t  MSG_REQ    = 1;
static constexpr uint8_t  MSG_RSP    = 2;
static constexpr uint8_t  MSG_BURN   = 4;
static constexpr uint8_t  MSG_REQX   = 12;
static constexpr uint8_t  MSG_BURNACK = 14;
static constexpr uint8_t  MSG_PROT   = 0x80;
static constexpr uint8_t  MSG_SPND   = 0x82;

static constexpr uint16_t RESP_TABLE_SIZE   = 256;
static constexpr uint16_t RESP_PORT_OFFSET  = 75;
static constexpr uint8_t  RESP_PORT_FAN_BIT = 0x80;

enum OutMode : uint8_t { OM_OFF = 0, OM_MAN = 1, OM_TEMP = 2, OM_RPM = 3 };

enum WarnBit : uint16_t {
    W_IDLE_LO = 1 << 0,
    W_IDLE_HI = 1 << 1,
    W_OVERREV = 1 << 2,
    W_OVERHEAT = 1 << 3,
    W_HOTAIR = 1 << 4,
    W_LOWBATT = 1 << 5,
    W_HIBATT = 1 << 6,
    W_OVERBOOST = 1 << 7,
    W_LEAN = 1 << 8,
    W_RICH = 1 << 9,
};

struct EngineProfile {
    bool    enabled = true;
    int16_t idleRpmMin = 700;
    int16_t idleRpmMax = 1100;
    int16_t maxRpm = 8000;
    int16_t cltMax = 2300;
    int16_t matMax = 1600;
    int16_t battMin = 110;
    int16_t battMax = 160;
    int16_t mapMax = 2800;
    int16_t afrLow = 100;    // below this = RICH
    int16_t afrHigh = 165;   // above this = LEAN
    uint16_t warnHoldMs = 3000;
    uint8_t  warnOut = 0;
};

struct PinMap {
    uint8_t iac = PIN_IAC_DEF;
    uint8_t out[7] = { PIN_O1_DEF, PIN_O2_DEF, PIN_O3_DEF, PIN_O4_DEF, PIN_O5_DEF, PIN_O6_DEF, PIN_O7_DEF };
};

static constexpr uint16_t CFG_MAGIC = 0x4963;

struct Cfg {
    uint16_t magic = CFG_MAGIC;
    PinMap pin;
    bool    tftEnable = false;
    int16_t fanOnTemp = 2000;
    int16_t fanOffTemp = 1900;
    bool    fanAuto = true;
    bool    fanManual = false;
    int16_t iacTargetRpm = 900;
    uint8_t iacFailDuty = 0;
    bool    iacAuto = true;
    bool    iacFollow = false;
    uint8_t iacManualDuty = 30;
    int16_t shiftRpm = 7000;
    uint8_t outMode[7] = { OM_RPM, OM_OFF, OM_OFF, OM_OFF, OM_OFF, OM_OFF, OM_OFF };
    int16_t outTemp[7] = { 0, 0, 0, 0, 0, 0, 0 };
    int16_t outRpm[7]  = { 7000, 0, 0, 0, 0, 0, 0 };
    bool    outManual[7] = { false, false, false, false, false, false, false };
    bool    anEnable[4] = { false, false, false, false };
    uint16_t anThresh[4] = { 0, 0, 0, 0 };
    uint8_t anOut[4] = { 0, 0, 0, 0 };
    uint8_t fanOut = 6;
    bool    respEnable = false;
    uint8_t respId = 5;
    EngineProfile eng;
};

static constexpr uint8_t kIacTempF[8] = { 50, 80, 100, 120, 140, 160, 180, 200 };
static constexpr uint8_t kIacDuty[8]  = { 60, 55, 50, 45, 40, 35, 30, 28 };

static Cfg        g_cfg;
static Preferences g_prefs;
static const char* const kPrefsName = "iobox";

static uint8_t  s_outpc[72];
static bool     s_groupSeen[9] = { false, false, false, false, false, false, false, false, false };
static uint32_t s_lastFrameMs = 0;
static bool     s_canFresh = false;
static bool     s_anyGroupSeen = false;

static uint8_t  s_respTable[RESP_TABLE_SIZE];
static uint8_t  s_respPort[3] = { 0, 0, 0 };
static uint16_t s_respPortBase = RESP_PORT_OFFSET;
static bool     s_respPortBaseSet = false;
static bool     s_respPortsFresh = false;
static uint32_t s_respLastFrameMs = 0;

static constexpr uint8_t ADC_PINS[4] = { PIN_A1, PIN_A2, PIN_A3, PIN_A4 };

static uint16_t rdU16(uint8_t off) { return (uint16_t)((s_outpc[off] << 8) | s_outpc[off + 1]); }
static int16_t  rdS16(uint8_t off) { return (int16_t)rdU16(off); }

static uint32_t g_rpm = 0;
static int16_t  g_map = 0, g_mat = 0, g_clt = 0, g_tps = 0, g_batt = 0, g_afr = 0;
static int16_t  g_iacStep = 0;

static uint8_t interpolateIac(int16_t cltF) {
    if (cltF <= kIacTempF[0]) return kIacDuty[0];
    for (uint8_t i = 1; i < 8; i++) {
        if (cltF <= kIacTempF[i]) {
            int16_t x0 = kIacTempF[i - 1], x1 = kIacTempF[i];
            int16_t y0 = kIacDuty[i - 1], y1 = kIacDuty[i];
            return (uint8_t)(y0 + (y1 - y0) * (cltF - x0) / (x1 - x0));
        }
    }
    return kIacDuty[7];
}

static void setFan(bool on) {
    if (g_cfg.fanOut >= 1 && g_cfg.fanOut <= 7) digitalWrite(g_cfg.pin.out[g_cfg.fanOut - 1], on ? HIGH : LOW);
}
static void setOut(uint8_t i, bool on) { digitalWrite(g_cfg.pin.out[i], on ? HIGH : LOW); }
static void setIac(uint8_t duty) { ledcWrite(0, (uint32_t)duty * 1023 / 100); }

static uint16_t readAnalogMv(uint8_t i) {
    return (uint16_t)(analogRead(ADC_PINS[i]) * 3300.0f / 4095.0f * ADC_DIVIDER);
}

static const char* tgtName(uint8_t t) {
    static char buf[8];
    if (t == 0) return "-";
    if (t == 7) return "fan";
    snprintf(buf, sizeof buf, "O%u", t);
    return buf;
}

static bool s_anLatch[4] = { false, false, false, false };

static void updateAnalogLatch() {
    for (uint8_t i = 0; i < 4; i++) {
        if (!g_cfg.anEnable[i]) { s_anLatch[i] = false; continue; }
        int16_t t = (int16_t)g_cfg.anThresh[i];
        int16_t mv = (int16_t)readAnalogMv(i);
        int16_t lo = t > 150 ? t - 150 : 0;
        if (!s_anLatch[i] && mv >= t) s_anLatch[i] = true;
        else if (s_anLatch[i] && mv <= lo) s_anLatch[i] = false;
    }
}

static bool inputForces(uint8_t target) {
    if (target == 0) return false;
    for (uint8_t i = 0; i < 4; i++) {
        if (g_cfg.anOut[i] == target && g_cfg.anEnable[i] && s_anLatch[i]) return true;
    }
    return false;
}

static void outputsOff() {
    setFan(false);
    for (uint8_t i = 0; i < 7; i++) setOut(i, false);
}

static void handleCommand(const String& line);
static bool pinOk(uint8_t p);
static void applyPinConfig();

struct RespHeader {
    uint16_t offset;
    uint8_t  type;
    uint8_t  from;
    uint8_t  to;
    uint8_t  table;
};

static uint32_t respMakeId(uint16_t offset, uint8_t type, uint8_t from, uint8_t to, uint8_t table) {
    return ((uint32_t)(offset & 0x7FF) << 18)
         | ((uint32_t)(type & 0x07)   << 15)
         | ((uint32_t)(from & 0x0F)   << 11)
         | ((uint32_t)(to & 0x0F)     << 7)
         | ((uint32_t)((table & 0x0F) << 3))
         | ((uint32_t)((table & 0x10) >> 2));
}

static RespHeader respParseHeader(uint32_t id) {
    RespHeader h;
    h.offset = (uint16_t)((id >> 18) & 0x7FF);
    h.type   = (uint8_t)((id >> 15) & 0x07);
    h.from   = (uint8_t)((id >> 11) & 0x0F);
    h.to     = (uint8_t)((id >> 7)  & 0x0F);
    h.table  = (uint8_t)(((id >> 3) & 0x0F) | (((id >> 2) & 0x01) << 4));
    return h;
}

static uint16_t readAnalogMv(uint8_t i);

static void respSendReply(const RespHeader& req, uint16_t remOff, uint8_t remTable, uint8_t remBy) {
    if (remBy == 0 || remBy > 8) return;
    if ((uint16_t)(req.offset + remBy) > RESP_TABLE_SIZE) return;
    twai_message_t r = {};
    r.identifier = respMakeId(remOff, MSG_RSP, g_cfg.respId, req.from, remTable);
    r.extd = 1;
    r.data_length_code = remBy;
    for (uint8_t k = 0; k < remBy; k++) r.data[k] = s_respTable[req.offset + k];
    twai_transmit(&r, 0);
}

static void respPopulateAdc() {
    if (!g_cfg.respEnable) return;
    for (uint8_t i = 0; i < 4; i++) {
        uint16_t v = readAnalogMv(i);
        s_respTable[i * 2]     = (uint8_t)(v >> 8);
        s_respTable[i * 2 + 1] = (uint8_t)(v & 0xFF);
    }
}

static void readCan() {
    twai_message_t msg;
    while (twai_receive(&msg, 0) == ESP_OK) {
        if (msg.extd) {
            if (!g_cfg.respEnable) continue;
            RespHeader h = respParseHeader(msg.identifier);
            if (h.to != g_cfg.respId && h.to != 15) continue;
            switch (h.type) {
                case MSG_REQ: {
                    if (msg.data_length_code < 3) break;
                    uint8_t remTable = msg.data[0];
                    uint16_t remOff  = ((uint16_t)msg.data[1] << 3) | ((msg.data[2] & 0xE0) >> 5);
                    uint8_t  remBy   = msg.data[2] & 0x1F;
                    respSendReply(h, remOff, remTable, remBy);
                    break;
                }
                case MSG_CMD: {
                    uint8_t dlc = msg.data_length_code > 8 ? 8 : msg.data_length_code;
                    if ((uint16_t)(h.offset + dlc) <= RESP_TABLE_SIZE) {
                        memcpy(&s_respTable[h.offset], msg.data, dlc);
                    }
                    if (!s_respPortBaseSet && dlc >= 1 && dlc <= 3) {
                        s_respPortBase = h.offset;
                        s_respPortBaseSet = true;
                    }
                    if (dlc <= 3 && h.offset == s_respPortBase) {
                        memcpy(s_respPort, msg.data, dlc);
                        if (dlc < 3) memset(&s_respPort[dlc], 0, 3 - dlc);
                        s_respPortsFresh = true;
                        s_respLastFrameMs = millis();
                    }
                    break;
                }
                default:
                    break;
            }
            continue;
        }
        if (msg.identifier == CAN_CMD_ID) {
            String line;
            uint8_t n = msg.data_length_code > 8 ? 8 : msg.data_length_code;
            for (uint8_t i = 0; i < n; i++) {
                char ch = (char)msg.data[i];
                if (ch == '\0' || ch == '\n' || ch == '\r') break;
                line += ch;
            }
            handleCommand(line);
            continue;
        }
        if (msg.identifier < CAN_BASE_ID ||
            msg.identifier >= CAN_BASE_ID + CAN_GROUP_COUNT) continue;
        uint8_t grp = (uint8_t)(msg.identifier - CAN_BASE_ID);
        uint8_t dlc = msg.data_length_code > 8 ? 8 : msg.data_length_code;
        memcpy(&s_outpc[grp * 8], msg.data, dlc);
        if (dlc < 8) memset(&s_outpc[grp * 8 + dlc], 0, 8 - dlc);
        s_groupSeen[grp] = true;
        s_anyGroupSeen = true;
        s_lastFrameMs = millis();
    }
}

static void decodeOutpc() {
    if (s_groupSeen[0]) g_rpm  = rdU16(6);
    if (s_groupSeen[2]) {
        g_map  = rdS16(18);
        g_mat  = rdS16(20);
        g_clt  = rdS16(22);
    }
    if (s_groupSeen[3]) {
        g_tps  = rdS16(24);
        g_batt = rdS16(26);
        g_afr  = rdS16(28);
    }
    if (s_groupSeen[6]) g_iacStep = rdS16(54);
}

static uint16_t s_warnRaw = 0;
static uint16_t s_warnLatched = 0;
static uint32_t s_warnFirstMs = 0;

static const char* kTopWarnOrder[] = {
    "OVERHEAT", "OVERBOOST", "OVERREV", "LOWBATT", "HIBATT",
    "LEAN", "RICH", "HOTAIR", "IDLEHI", "IDLELO"
};

static const char* topWarnName(uint16_t raw) {
    static const uint16_t kPrio[] = { W_OVERHEAT, W_OVERBOOST, W_OVERREV, W_LOWBATT, W_HIBATT,
                                      W_LEAN, W_RICH, W_HOTAIR, W_IDLE_HI, W_IDLE_LO };
    for (uint8_t i = 0; i < 10; i++) {
        if (raw & kPrio[i]) return kTopWarnOrder[i];
    }
    return "";
}

static uint16_t engineWarnFlags() {
    uint16_t raw = 0;
    if (!s_canFresh) return 0;
    bool cltOk = s_groupSeen[2] && g_clt > 100 && g_clt < 3500;
    bool matOk = s_groupSeen[2] && g_mat > 0 && g_mat < 3000;
    bool onThrottle = s_groupSeen[3] && g_tps >= 50;
    bool afrOk = onThrottle && g_afr >= 100 && g_afr <= 250;

    if (g_rpm >= g_cfg.eng.maxRpm) raw |= W_OVERREV;
    if (g_rpm > 0 && g_rpm < g_cfg.eng.idleRpmMin && g_tps < 200) raw |= W_IDLE_LO;
    if (g_rpm > 0 && g_rpm > g_cfg.eng.idleRpmMax && g_tps < 200) raw |= W_IDLE_HI;
    if (cltOk && g_clt > g_cfg.eng.cltMax) raw |= W_OVERHEAT;
    if (matOk && g_mat > g_cfg.eng.matMax) raw |= W_HOTAIR;
    if (g_batt > 0 && g_batt < g_cfg.eng.battMin) raw |= W_LOWBATT;
    if (g_batt > 0 && g_batt > g_cfg.eng.battMax) raw |= W_HIBATT;
    if (s_groupSeen[2] && g_map > g_cfg.eng.mapMax) raw |= W_OVERBOOST;
    if (afrOk && g_afr > g_cfg.eng.afrHigh) raw |= W_LEAN;
    if (afrOk && g_afr < g_cfg.eng.afrLow) raw |= W_RICH;
    return raw;
}

static void updateEngineProfile() {
    s_warnRaw = engineWarnFlags();
    if (s_warnRaw) {
        if (!s_warnLatched) s_warnFirstMs = millis();
        s_warnLatched = s_warnRaw;
    } else if (s_warnLatched && (millis() - s_warnFirstMs) >= g_cfg.eng.warnHoldMs) {
        s_warnLatched = 0;
    }
}

static void updateOutputs() {
    bool respActive = g_cfg.respEnable && s_respPortsFresh &&
                      (millis() - s_respLastFrameMs) < FAILSAFE_MS;
    if (!s_canFresh && !respActive) {
        outputsOff();
        setIac(g_cfg.iacFailDuty);
        return;
    }
    int16_t clt = g_clt;
    bool cltOk = s_groupSeen[2] && clt > 100 && clt < 3500;

    bool fanOn = false;
    if (respActive) {
        fanOn = (s_respPort[1] & RESP_PORT_FAN_BIT) != 0;
    } else if (g_cfg.fanAuto) {
        if (cltOk) {
            static bool fanState = false;
            if (!fanState && clt >= g_cfg.fanOnTemp) fanState = true;
            else if (fanState && clt <= g_cfg.fanOffTemp) fanState = false;
            fanOn = fanState;
        }
    } else {
        fanOn = g_cfg.fanManual;
    }
    fanOn = fanOn || inputForces(7);
    setFan(fanOn);

    for (uint8_t i = 0; i < 7; i++) {
        if ((i + 1) == g_cfg.fanOut) continue;
        bool on;
        if (respActive) {
            on = (s_respPort[1] & (1u << i)) != 0;
        } else {
            on = false;
            switch (g_cfg.outMode[i]) {
                case OM_OFF:  on = false; break;
                case OM_MAN:  on = g_cfg.outManual[i]; break;
                case OM_TEMP: on = cltOk && clt >= g_cfg.outTemp[i]; break;
                case OM_RPM:  on = s_groupSeen[0] && g_rpm >= g_cfg.outRpm[i]; break;
            }
        }
        on = on || inputForces(i + 1);
        setOut(i, on);
    }

    if (g_cfg.eng.warnOut >= 1 && g_cfg.eng.warnOut <= 7 &&
        g_cfg.eng.warnOut != g_cfg.fanOut && s_warnLatched) {
        bool blink = ((millis() / 500) & 1) == 0;
        setOut(g_cfg.eng.warnOut - 1, blink);
    }

    uint8_t duty;
    if (respActive) {
        duty = (uint8_t)constrain((int16_t)(s_respPort[0] * 100 / 255), 0, 100);
    } else if (g_cfg.iacFollow && s_groupSeen[6]) {
        duty = (uint8_t)constrain((int16_t)(g_iacStep * 100 / 255), 0, 100);
    } else if (g_cfg.iacAuto || (g_cfg.iacFollow && !s_groupSeen[6])) {
        if (!cltOk) {
            duty = interpolateIac(120);
        } else {
            duty = interpolateIac(clt / 10);
            int16_t err = g_cfg.iacTargetRpm - (int16_t)g_rpm;
            int16_t trim = constrain((int16_t)(err / 20), -5, 8);
            duty = constrain((int16_t)duty + trim, 5, 95);
        }
    } else {
        duty = g_cfg.iacManualDuty;
    }
    setIac(duty);
}

static void checkTwai() {
    twai_status_info_t st;
    if (twai_get_status_info(&st) == ESP_OK && st.state == TWAI_STATE_BUS_OFF) {
        twai_initiate_recovery();
    }
}

static void dashBroadcast() {
    twai_message_t m = {};
    m.identifier = CAN_DASH_ID;
    m.extd = 0;
    m.data_length_code = 8;
    m.data[0] = 0;
    for (uint8_t i = 0; i < 4; i++) {
        if (s_anLatch[i]) m.data[0] |= (uint8_t)(1u << i);
    }
    m.data[1] = 0;
    static uint8_t seq = 0;
    m.data[2] = ++seq;
    m.data[3] = (uint8_t)(s_warnLatched & 0xFF);
    twai_transmit(&m, 0);
}

static void drawGaugeFrame() {
    s_tft.fillScreen(GC9A01A_BLACK);
    s_tft.drawCircle(120, 120, 119, GC9A01A_NAVY);
    s_tft.drawCircle(120, 120, 118, GC9A01A_DARKGREY);
    s_tft.setTextColor(GC9A01A_CYAN);
    s_tft.setTextSize(2);
    s_tft.setCursor(96, 20);
    s_tft.print("IDLE");
    s_tft.setTextColor(GC9A01A_LIGHTGREY);
    s_tft.setTextSize(1);
    s_tft.setCursor(20, 130); s_tft.print("RPM");
    s_tft.setCursor(128, 130); s_tft.print("TGT");
    s_tft.setCursor(20, 168); s_tft.print("CLT");
    s_tft.setCursor(128, 168); s_tft.print("MODE");
}

static char s_lastDuty[8] = "";
static char s_lastRpm[8] = "";
static char s_lastTgt[8] = "";
static char s_lastClt[8] = "";
static char s_lastMode[8] = "";
static char s_lastStat[24] = "";
static char s_lastWarn[12] = "";

static void drawValue(int16_t x, int16_t y, uint8_t size, uint16_t color,
                      uint16_t clearW, char* last, const char* s) {
    if (strcmp(last, s) == 0) return;
    strcpy(last, s);
    s_tft.fillRect(x, y - 2, clearW, size * 8 + 4, GC9A01A_BLACK);
    s_tft.setCursor(x, y);
    s_tft.setTextSize(size);
    s_tft.setTextColor(color);
    s_tft.print(s);
}

static void updateDisplay() {
    if (!g_cfg.tftEnable) return;
    char buf[12];

    uint8_t duty = (uint8_t)(ledcRead(0) * 100 / 1023);
    snprintf(buf, sizeof buf, "%u%%", duty);
    drawValue(48, 48, 6, GC9A01A_CYAN, 144, s_lastDuty, buf);

    snprintf(buf, sizeof buf, "%u", s_canFresh ? g_rpm : 0);
    drawValue(20, 146, 2, s_canFresh ? GC9A01A_WHITE : GC9A01A_DARKGREY, 100, s_lastRpm, buf);

    snprintf(buf, sizeof buf, "%d", (int)g_cfg.iacTargetRpm);
    drawValue(128, 146, 2, GC9A01A_YELLOW, 100, s_lastTgt, buf);

    bool cltOk = s_groupSeen[2] && g_clt > 100 && g_clt < 3500;
    snprintf(buf, sizeof buf, cltOk ? "%dF" : "--", g_clt / 10);
    drawValue(20, 184, 2, cltOk ? GC9A01A_YELLOW : GC9A01A_DARKGREY, 100, s_lastClt, buf);

    bool respActive = g_cfg.respEnable && s_respPortsFresh &&
                      (millis() - s_respLastFrameMs) < FAILSAFE_MS;
    const char* mode = respActive ? "RMT" : (g_cfg.iacFollow ? "FOLLOW" : (g_cfg.iacAuto ? "AUTO" : "MAN"));
    snprintf(buf, sizeof buf, "%s", mode);
    drawValue(128, 184, 2, respActive ? GC9A01A_MAGENTA : GC9A01A_GREEN, 100, s_lastMode, buf);

    const char* warn = s_warnLatched ? topWarnName(s_warnLatched) : "";
    if (strcmp(s_lastWarn, warn)) {
        strcpy(s_lastWarn, warn);
        s_tft.fillRect(10, 202, 220, 10, GC9A01A_BLACK);
        if (s_warnLatched) {
            bool blink = ((millis() / 500) & 1) == 0;
            s_tft.setCursor(10, 202);
            s_tft.setTextSize(1);
            s_tft.setTextColor(blink ? GC9A01A_RED : GC9A01A_DARKGREY);
            s_tft.print(warn);
        }
    }

    uint16_t sc;
    if (!s_canFresh) {
        sc = GC9A01A_RED;
        snprintf(buf, sizeof buf, "CAN LOST");
    } else if (g_cfg.fanOut >= 1 && g_cfg.fanOut <= 7 && digitalRead(g_cfg.pin.out[g_cfg.fanOut - 1])) {
        sc = GC9A01A_GREEN;
        snprintf(buf, sizeof buf, "FAN ON  CAN OK");
    } else {
        sc = GC9A01A_LIGHTGREY;
        snprintf(buf, sizeof buf, "FAN OFF  CAN OK");
    }
    if (strcmp(s_lastStat, buf)) {
        strcpy(s_lastStat, buf);
        s_tft.fillRect(60, 212, 120, 10, GC9A01A_BLACK);
        s_tft.setCursor(60, 212);
        s_tft.setTextSize(1);
        s_tft.setTextColor(sc);
        s_tft.print(buf);
    }
}

static void initTft() {
    if (g_cfg.tftEnable) {
        s_tft.begin();
        s_tft.setRotation(0);
        s_tft.fillScreen(GC9A01A_BLACK);
        drawGaugeFrame();
        s_lastDuty[0] = s_lastRpm[0] = s_lastTgt[0] = s_lastClt[0] = 0;
        s_lastMode[0] = s_lastStat[0] = s_lastWarn[0] = 0;
    }
}

static void saveCfg() {
    g_prefs.putBytes("cfg", &g_cfg, sizeof(g_cfg));
}

static void loadCfg() {
    size_t len = g_prefs.getBytes("cfg", &g_cfg, sizeof(g_cfg));
    if (len != sizeof(g_cfg) || g_cfg.magic != CFG_MAGIC) {
        g_cfg = Cfg{};
        saveCfg();
    }
}
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
void loop() {
    respPopulateAdc();
    readCan();
    s_canFresh = s_anyGroupSeen && (millis() - s_lastFrameMs) < FAILSAFE_MS;
    decodeOutpc();
    updateAnalogLatch();
    updateEngineProfile();
    updateOutputs();
    checkTwai();

    static uint32_t ledLast = 0;
    uint32_t now = millis();
    uint32_t period = s_canFresh ? 1000 : 120;
    if (now - ledLast >= period) {
        ledLast = now;
        digitalWrite(PIN_LED, !digitalRead(PIN_LED));
    }

    static uint32_t dashLast = 0;
    if (now - dashLast >= DASH_TX_MS) {
        dashLast = now;
        dashBroadcast();
    }

    static uint32_t tftLast = 0;
    if (g_cfg.tftEnable && now - tftLast >= 100) {
        tftLast = now;
        updateDisplay();
    }

    if (Serial.available()) {
        static String line;
        while (Serial.available()) {
            char ch = (char)Serial.read();
            if (ch == '\n') { handleCommand(line); line = ""; }
            else if (ch != '\r') line += ch;
        }
    }

    delay(2);
}

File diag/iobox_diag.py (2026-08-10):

#!/usr/bin/env python3
"""iobox_diag - ESP32 MicroSquirt I/O box testing & configuration tool.

Connects to the ESP32 I/O box over USB serial or WiFi (TCP) and drives the
same text command interface the box exposes on its serial console.

Usage:
    python3 iobox_diag.py            # or python iobox_diag.py on Windows

Deps:
    pyserial (pip install pyserial)  # only needed for the USB path
"""

import queue
import socket
import threading
import tkinter as tk
from tkinter import ttk, messagebox, scrolledtext

try:
    import serial
    import serial.tools.list_ports as list_ports
except ImportError:
    serial = None

BAUD = 115200
DEFAULT_TCP_HOST = "192.168.4.1"
DEFAULT_TCP_PORT = 23


# ── Transport ──────────────────────────────────────────────────────────────
class IoBox:
    """Serial or TCP link to the box. Reader thread -> queue -> UI poll."""

    def __init__(self, on_line):
        self._on_line = on_line
        self._ser = None
        self._sock = None
        self._rx = queue.Queue()
        self._tx_lock = threading.Lock()
        self._stop = threading.Event()

    @property
    def connected(self):
        return self._ser is not None or self._sock is not None

    def _reader(self, readline, timeout_ok):
        # timeout_ok: a timed-out read just means "no data yet" (serial
        # returns b'' on timeout; TCP raises socket.timeout). Neither is a
        # closed link. Only a real error (or EOF on TCP) ends the reader.
        while not self._stop.is_set():
            try:
                line = readline()
            except socket.timeout:
                if timeout_ok:
                    continue
                break
            except Exception:
                break
            if not line:
                if timeout_ok:
                    continue
                break
            self._rx.put(line.decode("latin-1", "replace").rstrip("\r\n"))
        self._rx.put(None)

    def connect_serial(self, port):
        if serial is None:
            raise RuntimeError("pyserial not installed (pip install pyserial)")
        if self.connected:
            self.disconnect()
        self._stop.clear()
        self._ser = serial.Serial(port, BAUD, timeout=0.5)
        threading.Thread(target=self._reader,
                         args=(self._ser.readline, True), daemon=True).start()

    def connect_tcp(self, host, port):
        if self.connected:
            self.disconnect()
        self._stop.clear()
        self._sock = socket.create_connection((host, port), timeout=5)
        self._sock.settimeout(0.5)
        self._tcp_file = self._sock.makefile("rb")
        threading.Thread(target=self._reader,
                         args=(self._tcp_file.readline, True), daemon=True).start()

    def disconnect(self):
        self._stop.set()
        if self._ser:
            try:
                self._ser.close()
            except Exception:
                pass
            self._ser = None
        if self._sock:
            try:
                self._sock.close()
            except Exception:
                pass
            self._sock = None

    def send(self, cmd):
        if not self.connected:
            return False
        data = cmd.encode("latin-1") + b"\n"
        try:
            with self._tx_lock:
                if self._ser:
                    self._ser.write(data)
                else:
                    self._sock.sendall(data)
        except Exception:
            self._rx.put(None)
            return False
        return True

    def poll(self):
        """Drain queued lines; returns a list of lines + disconnect sentinel."""
        lines = []
        done = False
        while True:
            try:
                item = self._rx.get_nowait()
            except queue.Empty:
                break
            if item is None:
                done = True
            else:
                lines.append(item)
        return lines, done


# ── App ────────────────────────────────────────────────────────────────────
class App:
    def __init__(self, root):
        self.root = root
        self.root.title("I/O Box Diagnostic - ESP32 MicroSquirt")
        self.root.geometry("860x680")
        self.box = IoBox(self.on_line)

        self._build_ui()
        self._poll()

    # ---- UI --------------------------------------------------------------
    def _build_ui(self):
        pad = {"padx": 6, "pady": 4}

        # Connection bar
        conn = ttk.LabelFrame(self.root, text=" Connection ")
        conn.pack(fill="x", padx=8, pady=6)

        self.mode = tk.StringVar(value="serial")
        self.wifi_radio = ttk.Radiobutton(conn, text="WiFi", variable=self.mode,
                        value="wifi", command=self._mode_changed, state="disabled")
        self.wifi_radio.grid(
            row=0, column=0, sticky="w", **pad)
        ttk.Label(conn, text="WiFi pending (firmware)").grid(row=0, column=5, sticky="w")

        ttk.Label(conn, text="Host:").grid(row=0, column=1, sticky="e")
        self.tcp_host = ttk.Entry(conn, width=16)
        self.tcp_host.insert(0, DEFAULT_TCP_HOST)
        self.tcp_host.grid(row=0, column=2, sticky="w")

        ttk.Label(conn, text="Port:").grid(row=0, column=3, sticky="e")
        self.tcp_port = ttk.Entry(conn, width=6)
        self.tcp_port.insert(0, str(DEFAULT_TCP_PORT))
        self.tcp_port.grid(row=0, column=4, sticky="w")

        ttk.Radiobutton(conn, text="USB", variable=self.mode,
                        value="serial", command=self._mode_changed).grid(
            row=1, column=0, sticky="w", **pad)

        self.port_cb = ttk.Combobox(conn, width=24, state="readonly")
        self.port_cb.grid(row=1, column=1, columnspan=3, sticky="w")
        ttk.Button(conn, text="Refresh", command=self._refresh_ports).grid(
            row=1, column=4, **pad)

        self.connect_btn = ttk.Button(conn, text="Connect",
                                      command=self._toggle_connect)
        self.connect_btn.grid(row=0, column=6, rowspan=2, padx=12)

        self.status_lbl = ttk.Label(conn, text="Not connected", foreground="#888")
        self.status_lbl.grid(row=2, column=0, columnspan=7, sticky="w", padx=6)

        # Tabs
        nb = ttk.Notebook(self.root)
        nb.pack(fill="both", expand=True, padx=8)
        self._tab_fan = self._build_fan(nb)
        self._tab_iac = self._build_iac(nb)
        self._tab_out = self._build_outputs(nb)
        self._tab_in = self._build_inputs(nb)
        self._tab_eng = self._build_engine(nb)
        self._tab_pins = self._build_pins(nb)
        self._tab_adv = self._build_advanced(nb)
        nb.add(self._tab_fan, text=" Fan ")
        nb.add(self._tab_iac, text=" IAC ")
        nb.add(self._tab_out, text=" Outputs ")
        nb.add(self._tab_in, text=" Inputs ")
        nb.add(self._tab_eng, text=" Engine ")
        nb.add(self._tab_pins, text=" Pins ")
        nb.add(self._tab_adv, text=" Advanced ")
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

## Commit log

2026-08-06 ESP32 MicroSquirt I/O box: firmware, iobox2 PCB, Windows diag app, docs
    [iobox2.kicad_pcb, iobox2.kicad_sch]
2026-08-09 Add iobox3 (v3) firmware: configurable pins, 7 outputs, no display; update iobox2 + diag app
    - firmware-v3/: iobox3 board firmware (IAC19 + O1-O7 13/12/14/27/26/25/33 defaults,
    P command + NVS pin map, pinOk validation, no GC9A01/switches)
    - firmware/: iobox2 brought up to date (engine profile W commands, 0x710 byte3)
    - diag/: Pins tab (board presets, read/apply/reset), Engine tab, 7 outputs
    - READMEs: two-variant layout, cheat sheet for W/P commands
    [iobox_diag.py, main.cpp]
2026-08-09 diag: fix instant link-loss on connect (reader timeout was treated as EOF)
    Serial readline() returns b'' on its 0.5s timeout; the reader thread treated
    that as a closed link and dropped the connection immediately on connect. Now
    timeouts mean keep-waiting; only real errors/EOF end the reader. TCP path
    handles socket.timeout the same way.
    [iobox_diag.py]
2026-08-09 v3 fw: merge round display + D1-D3 switches into single firmware
    - GC9A01A idle gauge (duty%, RPM/TGT/CLT/MODE, warn blink, CAN status)
    and switch inputs ported from iobox2; adapted to 7 outputs + configurable pin map
    - Display is opt-in via 'P TFT 1' (CFG_MAGIC 0x4962) so GPIO19 (TFT DC vs
    iobox3 IAC) can't clash; iobox2 preset enables it, iobox3 keeps it off
    - 'D<n> 0|F|O<k>' maps switches to any output or fan; states ride 0x710 byte 1
    - '?' now reports d1-d3; platformio.ini gains GFX + GC9A01A libs
    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
2026-08-10 fw: remove D1-D3 switch inputs from both firmwares (no switches on board)
